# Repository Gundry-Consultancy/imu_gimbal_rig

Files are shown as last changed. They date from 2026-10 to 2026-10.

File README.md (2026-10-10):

# IMU gimbal rig

Pan / tilt / roll rig that carries a whole set of Adafruit IMU, accelerometer
and magnetometer breakouts (3/6/9 DoF) at once, with a cam-driven striker for
tap and double-tap detection testing.

Target sensors: the drivers added in
[adafruit/Adafruit_Wippersnapper_Arduino#839](https://github.com/adafruit/Adafruit_Wippersnapper_Arduino/pull/839)
(ISM330DHCX, ISM330DLC, LIS2MDL, LIS3DH, LIS3MDL, LSM303AGR, LSM303DLH,
LSM6DS3, LSM6DSO32, LSM9DS1). Mostly STEMMA QT breakouts, the odd legacy board,
and one FeatherWing.

## Requirements

- Every sensor is mounted at the same time, on stacked layers of swirly-grid
  plates ([tannewt/swirly-grid](https://github.com/tannewt/swirly-grid)). The
  sides stay open, with a small roof in the middle of the top to whack on. A
  swirly-grid PCB also bolts on through the matching slots.
- Only the centre plate connects to the roll servo and axle. The other plates
  hang off it on central standoffs in line with the roof, not at the edges.
- STEMMA QT sized breakouts, 4 across, plus a Feather-sized place for one
  FeatherWing.
- Hobby servos: MG90S (roll, and an MG90S-size 270° servo for the striker
  cam) and DS3240MG (tilt and pan). Both are measured; see
  `docs/servo-measurements.png`.
- Aim for ±180° on every axis. In practice the servo travel limits it.
- Sensors do not need to sit on the rotation centre. Off-axis
  acceleration is accepted.

## Sensor stack (`make_sensor_stack.py`)

Each deck is a 5 x 4 cell swirly grid (76.2 x 61 mm) with a 3 mm border. The
sides are open.

| Deck | Boards |
|---|---|
| top | 8 portrait QT around a central post with a flared **roof** (24 mm square) for the striker |
| middle | FeatherWing on 10 mm standoffs (clears header pins) + 1 QT, and 4 QT. Its +X / -X end walls (6 mm, with a rib and boss behind the hub) carry the MG90S roll horn and the idler axle. This is the only deck connected to the gimbal. |
| bottom | 8 portrait QT |

That is room for **21 QT boards + 1 FeatherWing**. PR 839 needs 9 breakouts + the wing.

- **Board layout:** boards sit portrait, 4 across, in two rows per deck. Each
  uses the QT connector on its outer edge, so cables leave through the open
  ±Y sides.
- **Fixing:** each board bolts through its top-edge hole pair (every QT board
  has it), with M2.5 screws, 3 mm spacers and nuts.
- **Spines:** a solid strip runs between the two rows on every deck. The upper
  and lower spines (36 x 7 mm standoffs) sit on it, directly under the roof.
- **Clamping:** two M3 bolts at x = ±14 run through the whole stack, with the
  heads on top, just outside the roof, and nuts underneath. The top and bottom
  decks have bosses round the bolt holes (6 mm there instead of 3), so washers
  are optional.
- **Mux:** you'll need a TCA9548A, because of I²C address clashes (several
  LIS3MDL/LSM303/LSM9DS1 parts share addresses). It fits in a spare board spot.

`pack_faces.py` checks the board placements against the slot geometry.

## Tap striker (`make_striker.py`)

**Redesigned 2026-10-10 so the gimbal can tilt all the way over.** The old
hairpin bar hovered just above the roof and limited tilt to ±55°. Now a rigid
hammer arm pivots on top of a tower on the pan yoke. When parked, it swings
up and well clear of the whole tilt sweep.

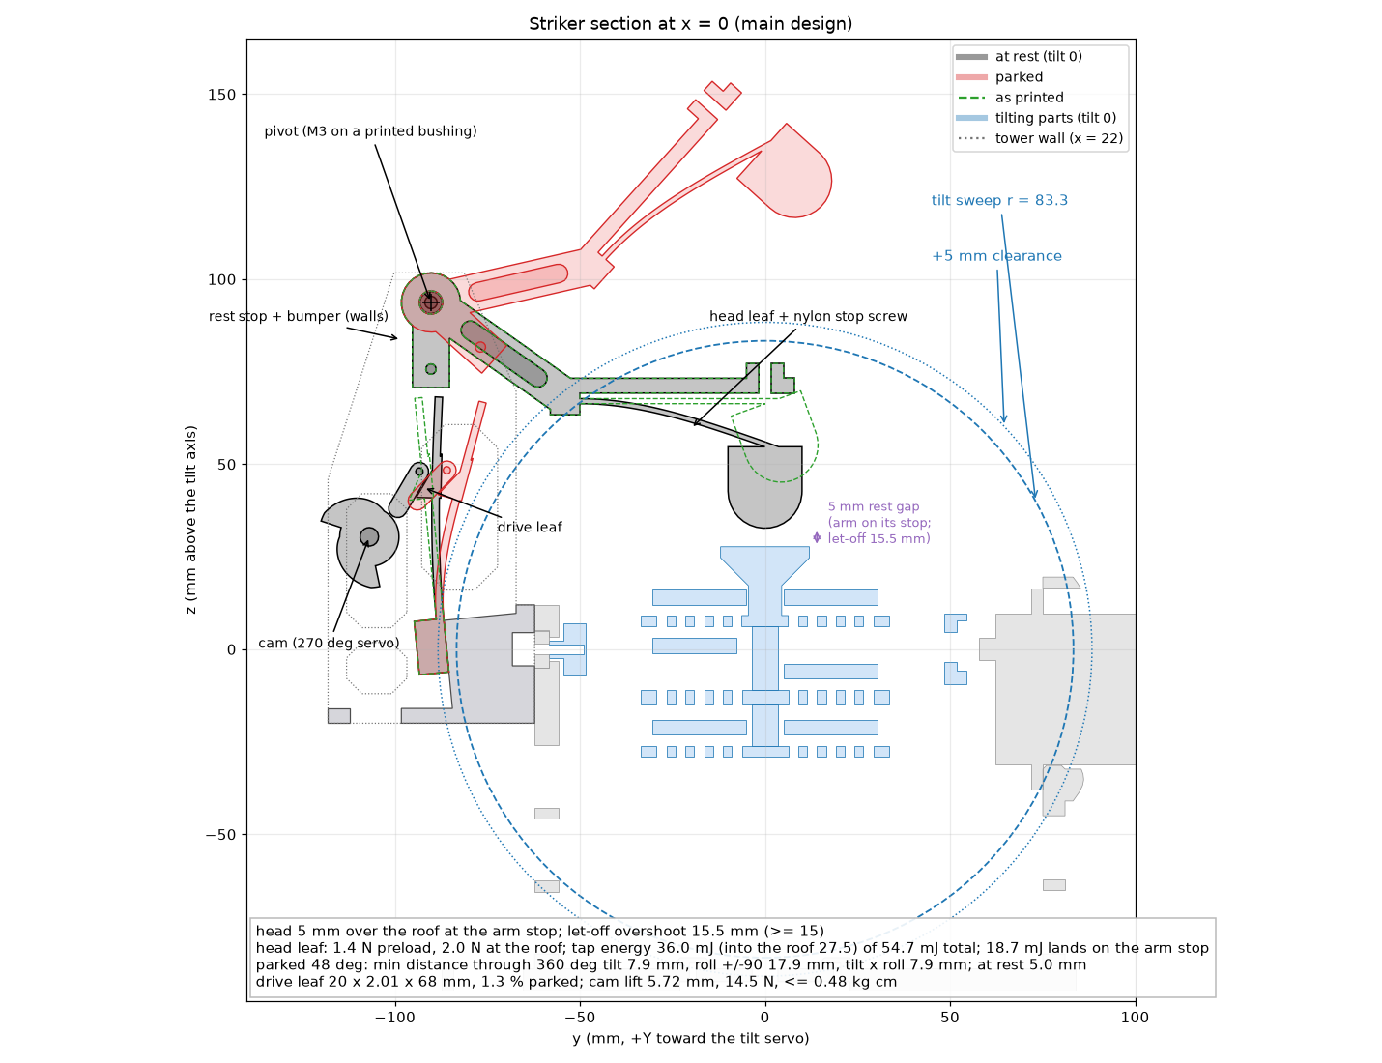
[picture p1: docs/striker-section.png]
striker section


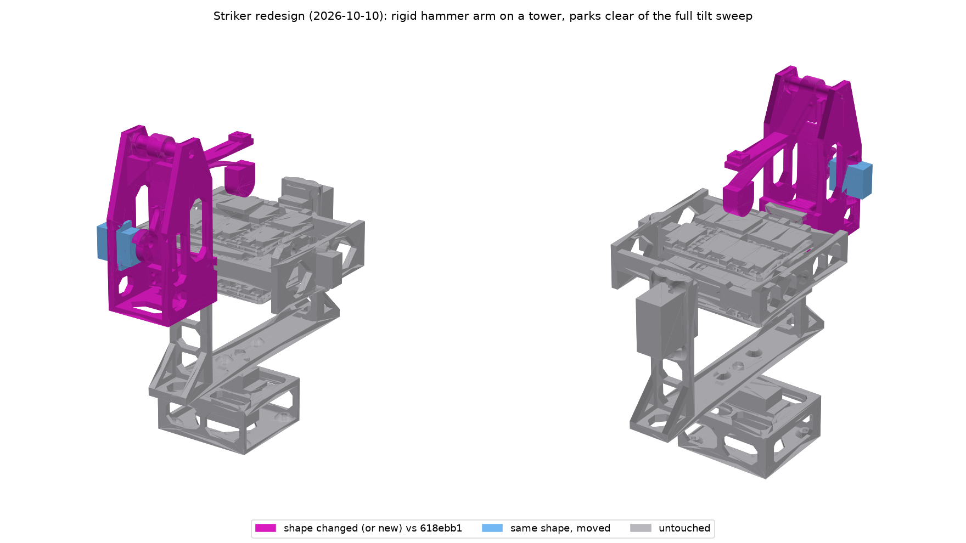
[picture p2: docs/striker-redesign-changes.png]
striker changes


**Parts:**
- **Tower** (`striker_stand`): bolts to the yoke's idler upright with the
  same 4 x M3 as before. Everything on it stays behind the ring band
  (y < −62 mm), so nothing on it can meet the ring when it tilts.
- **Hammer arm** (`striker_arm`): pivots on an M3 x 50 bolt, through a printed
  bushing and two spacers, about 66 mm above the roof.
- **Drive leaf** (`striker_spring`): a PETG strip standing on a seat at the
  bottom of the tower. Its tip fork is pinned (M3) to the arm's tail.
- **Cam:** the 270° servo's two-lobe cam bends the drive leaf through a
  folding pawl.

**How it works:**
- **Rest:** the drive leaf pushes the tail back, and the tail lands on a
  rest stop between the walls (with a 2 mm bumper lip). The hammer head then
  hovers **5 mm above the roof**. The servo carries no load at rest:
  the pawl sits 0.4 mm clear of the cam's base circle.
- **Park:** the cam bends the leaf, which swings the arm **48° up**.
  The parked arm clears everything that moves through the full 360° of tilt.
- **Tap:** at a cliff the pawl drops off the cam. The leaf throws the arm
  down onto its rest stop, and the stop takes the arm's energy.
- **Let-off:** the head sits on its own thin PETG leaf (lost motion). A nylon
  M3 screw in the overarm presses the leaf down, preloading it **1.4 N**
  against the screw. When the arm stops, the head's momentum carries it on
  through the 5 mm gap to the roof (**2.0 N** of leaf force at
  contact). Then it springs back onto the screw. The preload keeps it from
  bouncing back into the roof for a second tap.
- **Energy:** the drop releases **54.7 mJ** in all.
  - **36 mJ** is the head's share. That's what the tap carries
    (**27.5 mJ** is left at the roof after the leaf work).
  - The arm's **18.7 mJ** goes into the tower's rest stop, not the
    sensor stack.
- **Let-off margin:** the head could travel **15.5 mm** past the arm
  stop if the roof weren't there. That's ≥ 3 x the 5 mm gap, so the tap
  always lands.
- **Pawl:** pinned with 1.75 mm filament. It points at the cam centre and
  leans 16° past the cam's force line onto a stop under it. The cam's push,
  its forward drag and gravity all hold it there. On the reverse stroke the
  cliffs fold it up and back, and gravity drops it back.
- **Two lobes in the 270° travel.** Forward is −X rotation (seen from +X,
  the cam turns clockwise). If your servo runs the other way, flip the
  angles in software.

  | Action | Servo |
  |---|---|
  | rest, hammer hovering | 0° |
  | park for a double tap | ~120° |
  | park for a single tap | ~240° |
  | double tap | sweep forward through 125° and 245° (about 0.2 s apart at full MG90S speed) |
  | single tap | from 240°, step past 245° |
  | re-arm | back to 0°, then forward to a park angle |

  **Keep the hammer parked whenever the gimbal moves.**

**Computed for E = 2 GPa** (spring models in `leaf_design()` and
`head_leaf_design()`):

| | |
|---|---|
| drive leaf | 20 x 2.01 x 68 mm. 1.69 N at rest, 5.13 N parked at the pin; 1.3 % peak strain parked. The seat leans back 5.57° so a straight print is preloaded |
| head leaf | 12 x 1.36 x 50 mm, k = 0.12 N/mm, preloaded 11.7 mm by the stop screw; 1.36 % strain at contact |
| arm | 20.2 g; the head is 0.66 of its moment of inertia |
| cam | lift 5.72 mm (r 8 → 13.7). 14.5 N on the pawl when parked (the old bar: 14 N); servo torque ≤ 0.48 kg·cm |

**Clearance** (`striker_limits()` in `make_gimbal.py`: `distToShape`
against everything that moves, 5° steps). Each limit is ≥ 5 mm.

| | tilt 360° (parked) | roll ±90° (parked) | tilt 360° x roll ±45/±90° (parked, 15° steps) | at rest, tilt 0 / roll 0 |
|---|---|---|---|---|
| main | **7.9 mm** (clear through 360°) | 17.9 mm | 7.9 mm | 5.0 mm (the head over the roof) |
| `tall_top` | **7.9 mm** (clear through 360°) | 16.3 mm | 7.9 mm | 5.0 mm (the head over the roof) |

The ring's −Y axle stub is left out of these checks. It only spins inside the yoke's bearing, and its 4.5 mm to the tower's axle-screw pocket is set by the yoke (unchanged).

**At rest, apart from the roof** (main and `tall_top` alike), the nearest
moving part to each striker piece is:
- head: a top-deck QT board, 17.0 mm
- head leaf: 42.0 mm
- arm: 47.6 mm

The rest of the striker is at least 7.9 mm from anything that moves.

**Tuning:**
- The tap energy, contact force, gap and let-off margin are `TAP_ENERGY`,
  `F_CONTACT`, `HOVER` and `OVERSHOOT_MIN` at the top of `make_striker.py`.
  The leaves are re-solved from those values.
- On the bench, the stop-screw nuts trim the head preload. A thin shim on
  the rest-stop lip trims the hover gap.
- **Creep:** PETG relaxes under constant load. The drive leaf only carries
  much load while parked, and the stop screw takes up any creep in the head
  leaf.

**Printing:**
- `striker_arm` and `striker_spring` must be PETG, at 100 % infill.
  - `striker_arm` prints on its side (one 12 mm thick profile).
  - `striker_spring` prints flat, with its lugs and fork up.
- The tower prints upright, floor down. The pivot bosses are downward
  teardrops, and the walls stand vertical.

## Gimbal (`make_gimbal.py`)

Axes: roll = X, tilt = Y, pan = Z, all crossing in the stack. The script
measures the sweep radius of each stage to size the next one out. It then
rotates each stage through 360° against its neighbour, checks the striker
against the roll and tilt ranges, and reports any collision.

| Part | Holds | Servo | Idler |
|---|---|---|---|
| `stack_*` | all the boards | MG90S horn pocket on the middle deck's +X wall | M3 axle boss on the -X wall |
| `tilt_ring_mg90s` | roll servo + 623 bearing | MG90S (measured) | DS3240 horn on the +Y bar, M3 axle on -Y |
| `pan_yoke` | tilt servo + 623 bearing, outer gussets, striker stand pilots | DS3240MG on +Y | pan horn pocket underneath |
| `base` | pan servo | DS3240MG (270° version for ±135°) | open +X end for cables, 4 x M3 bench holes |
| `striker_*` | tower (stand), hammer arm, drive leaf, pawl, cam, pivot bushing + spacers | MG90S-size 270° servo | M3 pivot on a printed bushing |

**Servo mounts:** each mount sets its height from G (tab top to spline top),
taken as you measured it: MG90S 12.0, DS3240 14.0. If a servo sits a little
low, put a washer under its tabs. Every mount has a wire notch at the spline
end, 0.4 mm clearance, lead-in chamfers on both faces and bosses round the
screw pilots; see [Fit fixes](#fit-fixes-after-the-first-test-print).

The overall envelope is about 137 x 226 x 249 mm with the striker at rest
(about 300 mm tall with the hammer parked), and the printed parts weigh
about 376 g solid (305 g with the old striker, 349 g before the fit fixes).

### Fixings

Lengths come from the plate thicknesses in the model. Self-tap means a
machine or self-tapping screw cut straight into the printed pilot hole.

**Near the sensors, use non-magnetic fixings** (nylon, brass, or at least A2
stainless). Steel within a few cm of a magnetometer shows up as hard- and
soft-iron error.

| Where | Fixing | Qty | Notes |
|---|---|---|---|
| **Sensor stack** | M3 x 50 bolt (tall_top: M3 x 55) | 2 | top deck through both spines to the bottom deck at x = ±14; grip 44.3 mm (tall_top 52.2); **brass or nylon preferred** |
| | M3 nut (+ washers, optional) | 2 | nuts under the bottom deck's bosses, heads on the top deck's bosses just outside the roof. With tall_top's M3 x 55, leave the washers out |
| **QT boards** | M2.5 x 10 screw + nut + 3 mm spacer | 2 per board | top-edge hole pair; **nylon**. 9 boards in PR 839 = 18 sets (capacity 21 boards = 42) |
| **FeatherWing** | M2.5 x 10 standoff (F-F) + 2 x M2.5 x 6 screws + nut | 4 | nylon; 10 mm clears male headers |
| **Roll axis** | MG90S horn: supplied centre screw + 2 x M2 x 6 self-tap (arm) | 1 set | middle deck +X wall (4 mm behind the pocket floor) |
| | 623ZZ bearing + M3 x 12 button head + washer | 1 | tilt ring -X end, screw into the middle deck's -X axle boss |
| | MG90S tab screws: supplied, or 2 x M2 x 8–10 self-tap | 2 | tilt ring servo plate (1.7 mm pilots, 10 mm deep in the bosses) |
| **Tilt axis** | DS3240 horn: supplied centre screw + 2 x M2.5 x 8 self-tap (arm) | 1 set | tilt ring +Y bar |
| | 623ZZ bearing + M3 x 12 button head + washer | 1 | yoke -Y upright, screw into the ring's -Y axle boss |
| | DS3240 tab screws: supplied, or 4 x M2.6/M3 x 10–14 self-tap | 4 | yoke +Y plate (2.4 mm pilots, 12 mm deep in the bosses) |
| **Pan axis** | DS3240 horn: supplied centre screw + 2 x M2.5 x 8 self-tap (arm) | 1 set | yoke underside |
| | DS3240 tab screws: supplied, or 4 x M2.6/M3 x 10–12 self-tap | 4 | base plate (10 mm deep in the bosses) |
| | M3 x 16 (or #4 wood) screws, bench | 4 | base foot corners (3.5 mm holes through 6 mm bosses) |
| **Striker** | M3 x 14 (x 16 at most, with a washer) | 4 | tower to the yoke's idler upright (covers the tilt bearing), as before. Plate 10 mm at the bosses + upright 6.4 mm; longer pokes through toward the tilt ring. Reach the heads through the 7 mm holes in the leaf seat |
| | M3 x 50 + M3 nut | 1 | arm pivot: −X wall, `striker_bushing` (the arm and 2 spacers ride on it), +X wall. The nut drops into the hex pocket on the +X wall; tighten until snug, since the bolt clamps the walls onto the bushing, not the arm |
| | M3 x 20 | 1 | drive pin: through the drive leaf's fork slots, self-tapped into the arm's tail (2.8 mm pilot). Leave the head ~0.3 mm off the fork so the pin slides |
| | M3 x 16 | 4 | drive leaf root pad to the seat (self-tap into the 2.8 mm pilots) |
| | **M3 x 30 nylon** + 2 nylon M3 nuts | 1 | head stop screw: down through the overarm, one nut under the boss and one on top. The lower nut sets how far the screw presses the head leaf (11.7 mm preload). **Nylon:** it hangs right over the top deck |
| | MG90S-size 270° servo tab screws: supplied, or 2 x M2 x 8 self-tap | 2 | the tower's −X wall (servo plate) |
| | `striker_cam`: supplied centre screw, horn trimmed to 14 mm and **CA-glued** into the cam | 1 | the cam has no arm pilots |
| | `striker_cam_spline` instead: M2 x 10 centre screw | 1 | counterbored from the cam's front face |
| | 1.75 mm filament, ~12 mm | 1 | pawl pin; melt or flare the ends |
| **Printed horns** (if used) | MG90S: M2 x 8 centre screw; DS3240: M3 x 10 centre screw | per horn | longer than stock, because the printed hub is thicker |

**Bearings:** 2 x 623ZZ (3 x 10 x 4 mm).

**To order:** see [docs/shopping_list.md](docs/shopping_list.md), with quantities rounded to pack sizes.

**Totals for the main design, with 9 QT boards + wing:**
- **M3:**
  - M3 x 50: 3 (2 stack bolts, 1 striker pivot)
  - M3 x 12: 2 (axles)
  - M3 x 14: 4 (striker tower)
  - M3 x 16: 4 (drive leaf pad)
  - M3 x 20: 1 (drive pin)
  - M3 x 30 nylon + 2 nylon nuts: 1 (head stop screw)
  - M3 nuts: 3 (stack bolts, pivot)
  - M3 washers: ~2 (axles; the stack washers are optional)
  - bench screws (M3 x 16): 4
- **M2.5:**
  - M2.5 x 10: 18 (QT boards)
  - M2.5 x 6: 8 (wing)
  - M2.5 x 8 self-tap: 4 (horn arms)
  - M2.5 nuts: 22
  - 3 mm spacers: 18
  - 10 mm F-F standoffs: 4
- **M2:**
  - M2 x 6 self-tap: 2 (MG90S horn arms)
  - M2 x 8 self-tap: 4 (MG90S tabs, if not supplied)
  - M3 x 12 self-tap: 8 (DS3240 tabs, if not supplied)
- **Servo-supplied:** the horn centre screws and tab screws for 2 x MG90S and
  2 x DS3240.
- **Other:** 2 x 623ZZ bearings and a little 1.75 mm filament.

**Horns: two options, one set of parts.** Every horn pocket works either way.

1. **Stock horn.** The pockets are sized for an assumed double-arm horn:
   - MG90S: 36 x 7 mm, 2 mm deep, hub 2.5 mm
   - DS3240: 46 x 8.5 mm, 2.5 mm deep, hub 3.5 mm

   Each pocket has self-tap pilots 3.5 mm in from the arm tips. If your horn's
   holes land elsewhere, drill your own.
2. **Printed horn.** Print `horn_mg90s_printed` (21T) or `horn_ds3240_printed`
   (25T).
   - **Fit:** shaped to fill its pocket exactly, with a moulded spline socket,
     so it fits whatever the stock horns turn out to be.
   - **Screws:** an M2 (MG90S) or M3 (DS3240) screw through the hub into the
     spline, and M2 / M2.5 arm screws into the pocket pilots.
   - **Printing:** print arm-down, socket up, with fine layers (0.1–0.12 mm,
     a 0.25 mm nozzle if you have one).
   - **Fit tuning:** `SPLINE_CLEAR` in `make_gimbal.py` (0.1 mm radial)
     loosens or tightens the spline.

**The striker cam** has both versions too: `striker_cam` takes a stock horn
trimmed to 14 mm, and `striker_cam_spline` has the 21T socket moulded in
(M2 screw from the front, counterbored).

**Fitting a horn, either way:** screw the horn to the part, press it onto the
spline, then drive the centre screw through the part's access hole.

## Fit fixes after the first test print

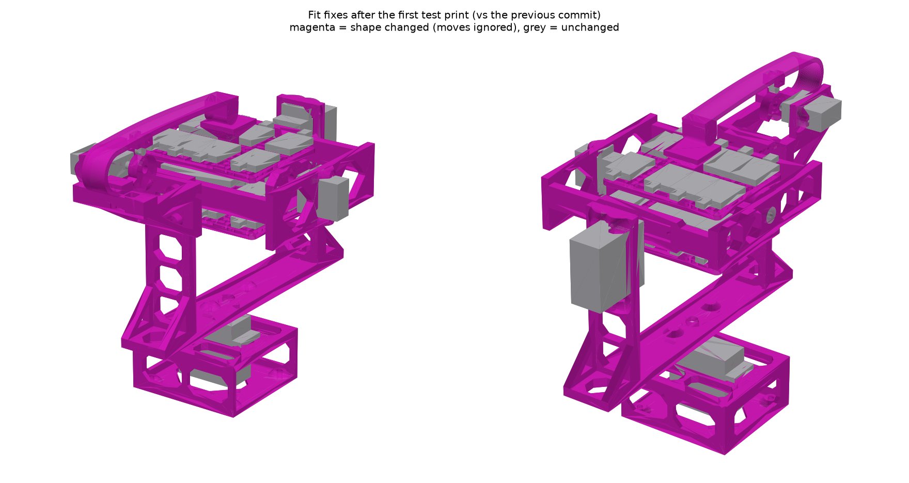
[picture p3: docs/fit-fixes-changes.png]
fit-fix changes


The first print failed in three ways:
- the servos would not go into their plates
- the plates and the tilt ring snapped at the screw pilots when they were
  flexed to get the servos in
- the middle deck's +X (horn) wall snapped along its top edge

Every fix is parametric. The servo-plate values are at the top of
`make_gimbal.py`, and the wall values at the top of `make_sensor_stack.py`.

| Problem | Fix | Parameters |
|---|---|---|
| The cable exit caught on the plate | A wire notch at the spline end of every body cut-out, through the plate and its bosses | `wire_notch` in the `MG90S` / `DS3240` dicts, `MOUSE_EAR_MIN_ARC` |
| The cut-out was too tight | 0.4 mm clearance per side (was 0.25), plus a 1 mm x 45° lead-in chamfer on **both** faces | `SERVO_CUT_CLEAR`, `SERVO_LEADIN` |
| Plates snapped at the pilots | 45° cone bosses on the side away from the tabs double the material round every tab pilot (the seat doesn't move). Bosses were also added at the striker-stand bolts, the stack bolt holes, the bench holes and the yoke's horn-arm pilots | `BOSS_FACTOR`, `BOSS_WALL` |
| The horn wall snapped | The wall is 6 mm thick (4 mm behind the pocket floor, was 2), wider than the horn arm and carried 8 mm above the axis with 45° shoulders. It has a rib and boss behind the hub and a flared root. The pocket has 45° roofs and the access hole is a teardrop, so nothing bridges when it prints walls-up | `WALL_T`, `WALL_ABOVE`, `RIB_*`, `ROOT_FLARE` |
| Thin bearing lips | Both 623 lips are 2.4 mm (were 2.0) | `RING_BRG_PLATE_T`, `YOKE_BRG_T` |
| Heavy parts | Windows in the low-stress webs of the ring, yoke, base and stand, with 45° tops so they print without support | `MAX_BRIDGE` |

**Wire notches and open-sided (mouse-ear) pilots.** A screw pilot sits right
where the cable leaves each servo, so the notch opens one side of that pilot
instead of leaving a paper-thin wall. At least 240° of wall stays round each
opened pilot (measured at mid-wall), and each one sits in a boss twice the
plate thickness.

| Plate | Servo | Notch | Pilots opened into the notch |
|---|---|---|---|
| `tilt_ring_mg90s` (roll) | MG90S | 6.0 mm wide, 1.1 mm past the cut-out (1.5 mm past the body end) | the one spline-end pilot (it's on the centreline) |
| `striker_stand` (cam) | MG90S | same | same |
| `pan_yoke` (tilt) | DS3240 | 8.0 mm wide, out to the tab end (7 mm past the body) | both spline-end pilots, inner side |
| `base` (pan) | DS3240 | same | same |

The MG90S notch is short because the spline-end screw sits on the centreline,
only ~1 mm past the body. If the cable still catches, there are two options:
- put the servo in from the other face (both faces are chamfered)
- lower `MOUSE_EAR_MIN_ARC` and give `wire_notch` a depth in mm. The build
  refuses a notch that opens a pilot past the limit.

**Which face each servo goes in from.** Turn each servo so the spline end (the
cable end) lines up with the notch.

| Servo | Plate | Goes in from | |
|---|---|---|---|
| roll MG90S | tilt ring, +X plate | inside the ring (the tab face), bottom first | the outer face also works (chamfered) |
| tilt DS3240 | yoke, +Y upright | the inner face (toward the ring), bottom first | tab face only |
| pan DS3240 | base, top plate | from above, bottom first | tab face only |
| cam MG90S | striker tower, −X wall | from inside the tower (the tab face), bottom first, before the leaf and cam go in; spline end (cable) up | the other face also works (chamfered) |

**Volume**, for the parts that were lightened or thickened:

| Part | Before (cm³) | After (cm³) | Change |
|---|---|---|---|
| `tilt_ring_mg90s` | 49.2 | 40.7 | −17 % |
| `pan_yoke` | 74.7 | 64.5 | −14 % |
| `base` | 54.9 | 36.0 | −34 % |
| `striker_stand` | 27.2 | 24.2 | −11 % |
| **those four** | **206.0** | **165.4** | **−20 %** |
| `stack_middle_deck` | 21.3 | 27.7 | +30 % (stronger walls) |
| `stack_top_deck` / `stack_bottom_deck` | 16.4 / 11.8 | 16.6 / 12.1 | bolt bosses |

**Envelope:** each middle-deck wall is 2 mm thicker. That makes the ring 4 mm
longer, puts the roll servo 2 mm further out and drops the yoke floor 2 mm.
The rig is now about 137 x 236 x 194 mm (was 132 x 236 x 192). The tilt range
with the striker fitted is unchanged.

**Not changed:**
- The tilt ring still needs supports: it's a closed frame, and its bars float
  above the bed.
- The tilt ring's DS3240 horn-arm pilots keep 3.5 mm behind the pocket floor.
  There's no room to thicken them: the horn is on the outside and the roll
  sweep margin is on the inside.
- The striker-stand pilots in the yoke's idler upright stay at the upright's
  6.4 mm. Only 1.5 mm separates it from the ring, so the stand side got the
  bosses instead.

## Print list

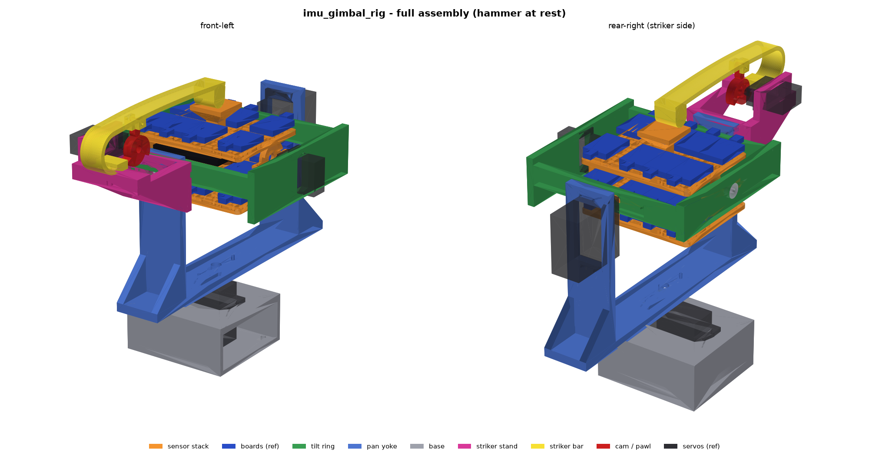
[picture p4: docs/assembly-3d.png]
assembly


All the STLs are in `parts/`. PETG is recommended throughout because it takes
the taps well. **The striker arm and drive leaf must be PETG.**

| STL | Qty | Nozzle | Orientation on the bed | Notes |
|---|---|---|---|---|
| `stack_bottom_deck` | 1 | 0.4 preferred | flat, **bolt bosses up** (upside down) | slots must pass M2.5; on 0.6, regenerate with `SWIRLY_SLOT=2.95` |
| `stack_middle_deck` | 1 | 0.4 preferred | flat, end walls up | carries the roll horn and axle. The horn pocket has 45° roofs and the access hole is a teardrop, so no supports; slot note as above |
| `stack_top_deck` | 1 | 0.4 preferred | flat, roof up | the roof flare is 45°, so no supports; slot note as above |
| `stack_spine_lower` | 1 | 0.6 | on its 36 x 7 face | **11.1 mm** tall (bottom ↔ middle deck) |
| `stack_spine_upper` | 1 | 0.6 | on its 36 x 7 face | **17.1 mm** tall (middle ↔ top deck); 25 mm in `variants/tall_top` |
| `tilt_ring_mg90s` | 1 | 0.6 | flat | **still needs supports** under the side bars and bearing plate (they sit ~10–15 mm up; it's a closed frame). Windows, bosses and pocket roofs are all 45°. Drill the 1.7 mm servo pilots |
| `pan_yoke` | 1 | 0.6 | on its side (32 mm face down) | the U profile lies flat, so no supports; windows have 45° tops (either side down); ream the 623 pocket if tight |
| `base` | 1 | 0.6 | on its closed end wall | open box, no supports; windows have 45° tops |
| `striker_stand` | 1 | 0.6 | **upright, floor down** (as it sits on the yoke) | the tower: walls stand vertical, the pivot bosses are downward teardrops and the rest stops have 45° undersides, so no supports. Windows have 45° tops. Drill the small pilots |
| `striker_arm` | 1 | 0.4 preferred | **on its side** (the 12 mm thick profile flat) | **PETG**, 100 % infill. The head leaf is 1.36 mm thick (its stiffness goes as thickness cubed; the stop screw trims the preload) |
| `striker_spring` | 1 | 0.4 preferred | **flat on its plain (+Y) face**, lugs and fork up | **PETG**, 100 % infill. The drive leaf: its 2.01 mm thickness sets the drive force (thickness cubed) |
| `striker_bushing` | 1 | 0.4 | standing on end | 6 mm tube for the M3 pivot bolt |
| `striker_spacer` | 2 | 0.4 | standing on end | either side of the arm's hub |
| `striker_pawl` | 1 | **0.4 needed** | flat on a 4.4 mm face | 1.9 mm pin hole must swing freely; pin is 1.75 mm filament. **Reprint it:** it is 14 mm long now (was 9) |
| `striker_cam` | 1 | 0.4 preferred | flat, **horn pocket up** | takes a stock horn trimmed to 14 mm; a crisp cliff edge gives a clean drop |
| `striker_cam_spline` | (alt.) | **0.4 needed** | counterbored face down, hub up | 21T socket moulded in; use instead of `striker_cam` |
| `horn_mg90s_printed` | 0–1 | **0.4 needed** (0.25 better) | arm down, socket up | 0.3 mm deep spline teeth; only if the stock roll horn doesn't fit |
| `horn_ds3240_printed` | 0–2 | **0.4 needed** | arm down, socket up | only if the stock tilt/pan horns don't fit |

**Nozzle key:**
- **0.6:** resolution doesn't matter. Thicker lines make these stronger and
  faster; drill or ream the small holes.
- **0.4 preferred:** fits or force depend on accuracy. A 0.6 works with the
  adjustment noted.
- **0.4 needed:** fine features (splines, the pawl pin) that a 0.6 smears.

The core set is 15 parts (16 prints with the second spacer), plus the optional printed horns. Print the horns
with fine layers (0.1–0.12 mm). Print one horn first and test it on a servo
before printing the others (`SPLINE_CLEAR`).

**Spine names were swapped before 2026-10-10.** Older exports of
`stack_spine_lower` were really the 17.1 mm upper spine, and vice versa.
Check the height before using an older print.

## Assembly order

Centre every servo (power it at mid travel) before you fit its horn. Each
horn goes on the same way: screw the horn to the part, press it onto the
spline, then drive the centre screw through the part's access hole.

1. **Test-fit each servo in its plate** before anything else. Put it in
   bottom first, from the face in the table above, with the cable end at the
   notch. Drill the pilots if they're tight.
2. **Base:** drop the pan DS3240 into the base from above. The cable leaves
   through the open +X end. Fit the 4 tab screws, then screw the base to the
   bench.
3. **Yoke:**
   - Put the tilt DS3240 into the +Y upright from the inside (bottom first,
     outward). Fit its 4 tab screws.
   - Press a 623 into the -Y upright from the outside.
   - Screw the pan horn into the underside pocket and press it onto the pan
     spline. Drive its centre screw down through the floor's access hole now,
     while nothing is above it.
4. **Tilt ring:**
   - Put the roll MG90S into the +X plate from inside the ring. Fit its 2 tab
     screws.
   - Press a 623 into the -X bearing plate from the outside.
   - Screw the tilt horn into the +Y bar's pocket.
5. **Sensor stack:**
   - Fit the boards to the decks.
   - Stack the decks: bottom deck (bosses down), lower spine, middle deck,
     upper spine, top deck (bosses up). Clamp them with the two M3 bolts.
   - Screw the roll horn to the middle deck's +X wall.
6. **Stack into the ring:**
   - Press the roll horn onto the MG90S spline and fit its centre screw
     through the wall's access hole.
   - At the -X end, fit an M3 x 12 + washer through the ring's 623 into the
     middle deck's axle boss.
7. **Ring into the yoke:**
   - Press the tilt horn onto the tilt spline and fit its centre screw through
     the bar's access hole.
   - At -Y, fit an M3 x 12 + washer through the yoke's 623 into the ring's
     axle boss.
8. **Striker** (everything goes into the tower before it goes onto the yoke):
   - Put the cam MG90S into the tower's −X wall from inside, bottom first,
     spline end (cable) up. Fit its 2 tab screws.
   - Pin the pawl to the drive leaf's lugs with filament. It should swing
     freely and fall back onto its stop.
   - Screw the drive leaf's root pad to the seat (4 x M3 x 16), lugs and
     pawl toward the servo.
   - Put the bushing through the arm's hub, with a spacer either side. Hold
     the arm between the walls and push the M3 x 50 through the −X wall,
     the bushing and the +X wall, into the nut in its pocket. Tighten until
     snug. The arm should swing freely.
   - Bend the leaf's fork onto the tail (the leaf leans back about 5.5° when
     free). Drive the M3 x 20 pin through one fork slot, self-tap it through
     the tail and out through the other slot. Leave the head ~0.3 mm clear,
     so the pin can slide.
   - Fit the nylon stop screw down through the overarm with a nut under the
     boss. Turn it until the head leaf is pressed down 11.7 mm (the head's
     face is level), then lock it with the top nut.
   - Fit the cam with the servo at 0°: the pawl tip just clears the base
     circle, 45° up from the cam's +Y side.
   - Bolt the tower to the yoke's -Y upright (4 x M3 x 14, reached through
     the holes in the leaf seat). This covers the tilt axle screw, so fit the
     tower last.
   - Check the hover gap: the head's face should sit 5 mm above the roof. To
     trim it, shim the rest-stop lip, where the tail lands.

## Variants

| Folder | What's different |
|---|---|
| [`variants/tall_top`](variants/tall_top/README.md) | Upper spine 25 mm. The top deck, roof and striker sit 7.9 mm higher. Only `stack_spine_upper` and `striker_stand` are new prints. |

## Files

| File | What |
| --- | --- |
| `swirly_grid.py` | Pure-Python swirly-grid geometry + hole-pattern fit checker (`python swirly_grid.py 2 4`) |
| `pack_faces.py` | Portrait QT board placement options on a swirly grid |
| `make_sensor_stack.py` | Sensor stack decks, spines, roof, board layout, reference board envelopes |
| `make_striker.py` | Striker: drive-leaf and head-leaf spring models, hammer arm (rest / parked / as printed), pawl, cam, tower |
| `make_gimbal.py` | Full gimbal + striker, per-part STEP/STL in `parts/`, clearance checks, `imu-gimbal-assembly.FCStd` |
| `make_swirly_plate.py` | Flat printable swirly plate (env `SWIRLY_ROWS`, `SWIRLY_COLS`, `SWIRLY_SLOT`) |
| `make_carrier.py` | Older standalone flat plate with Feather bosses (not used by the gimbal) |
| `preview_swirly.py` | Matplotlib 2D preview |
| `docs/mechanical_data.md` | Board hole/IC positions for the PR 839 sensors, Feather spec, servo dimensions |

Generate with FreeCAD 1.1 (`C:\dev\software\FreeCAD\bin\freecadcmd.exe`):

```
freecadcmd -c "exec(open('make_gimbal.py').read(), {'__file__': 'make_gimbal.py', '__name__': '__main__'})"
```

## Notes

- A 1.0" x 0.7" STEMMA QT board (holes 0.8" x 0.5" apart) cannot land all four
  screws in the swirly grid at once. Three holes fit in 32 placements on a
  3x3 grid, and two holes fit in hundreds. Plan on 2–3 screws per board.
- Slots print at 2.75 mm (nominal 2.54 mm) so M2.5 screws pass on FDM.

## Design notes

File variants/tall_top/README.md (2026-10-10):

# Variant: tall_top

This is the main design with more room between the middle and top decks. The
upper spine goes from 17.1 mm to **25 mm**. The bottom deck and lower spine
are unchanged, since the bottom deck isn't attached to the gimbal.

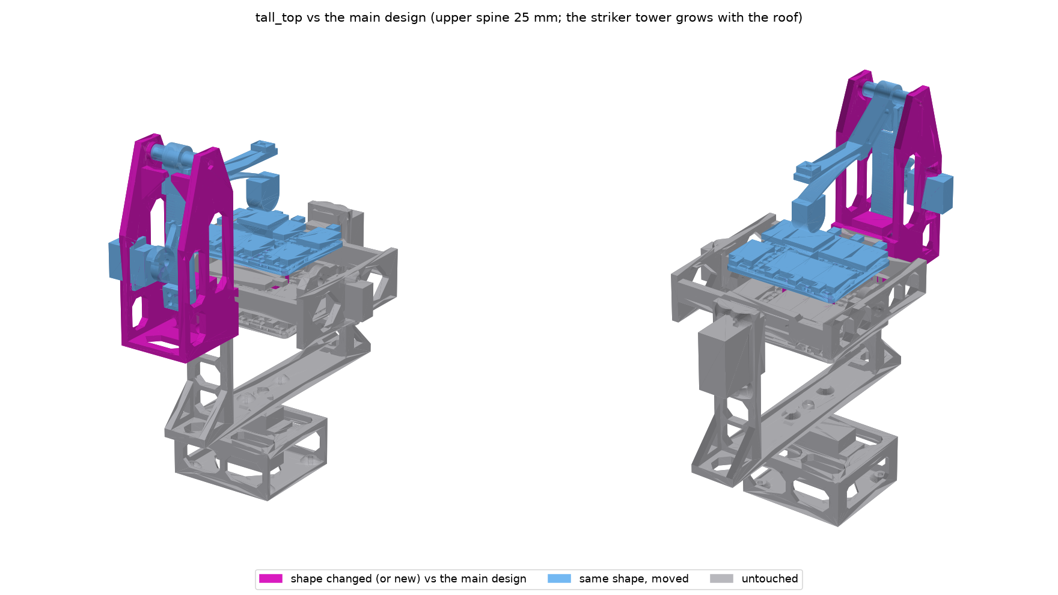
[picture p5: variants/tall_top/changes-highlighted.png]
changes


## What changed

**Modified parts (print these):**

| Part | Change |
|---|---|
| `stack_spine_upper` | 17.1 → **25.0 mm** tall |
| `striker_stand` | the striker tower is 7.9 mm taller (overall 121.7 → 129.6 mm). Its walls, leaf seat and servo plate all move up with the roof |

**Same parts, sitting 7.9 mm higher:** `stack_top_deck` (and its roof), and
the whole striker mechanism: `striker_arm`, `striker_spring`,
`striker_pawl`, `striker_cam` / `striker_cam_spline`, `striker_bushing`,
`striker_spacer` and the cam servo. The STLs are the same as the main
design's.

**Unchanged:**
- The middle deck and its roll walls, the roll axis, tilt ring, pan yoke, base,
  bottom deck, lower spine and horns (all as in the main design, including the
  2026-10-10 fit fixes).
- The ring and yoke sizes are pinned to the main build (`../../build_info.json`).

**Striker numbers are the same as the main design** (2026-10-10 redesign;
see the main README):
- The head hovers 5 mm above the roof at rest.
- The arm parks 48° up.
- Tap energy is 36 mJ of 54.7 mJ total; the arm's 18.7 mJ lands on the
  tower's rest stop.
- Let-off overshoot is 15.5 mm.

**Clearance checks:**
- All checks pass.
- **Roll through 360°:** the higher top deck's connectors clear the unchanged
  tilt ring by 2.4 mm. The main design allows 4 mm, so allow less cable slack
  on the top deck if you roll it all the way round. Within the MG90S's ±90°
  there's more room.
- **Striker (parked):**
  - **tilt clear through 360°**, min distance 7.9 mm
  - roll ±90°: 16.3 mm
  - tilt x roll ±45/±90°: 7.9 mm
- **Striker at rest:** 5.0 mm (the head over the roof). Apart from the roof: head 17.0 mm to the nearest QT board, head leaf 42.0 mm, arm 47.6 mm.

**Hardware differences from the main fixings list:**
- **Stack bolts:** M3 x 55 instead of x 50. The grip is 52.2 mm with the deck
  bolt bosses, so leave the washers out (the bosses replace them).
- **Striker:** the same fixings as the main design. The old `tall_top` M3 x 22
  pad screws are no longer used.

## If you've already printed the main design

Print only `stack_spine_upper` and `striker_stand` from `parts/` here.
Everything else carries over.

## Regenerate

From the repo root, after a main build (which writes `build_info.json`):

```
GIMBAL_OUT=variants/tall_top GIMBAL_PIN=build_info.json STACK_UPPER_GAP=25 freecadcmd -c "exec(open('make_gimbal.py').read(), {'__file__': 'make_gimbal.py', '__name__': '__main__'})"
```

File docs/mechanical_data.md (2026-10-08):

# Mechanical reference data

Coordinates are mm from the board's lower-left corner, in the orientation the
Eagle `.brd` draws it. Hole and IC positions were parsed from the Adafruit PCB
repos. All boards are 1.6 mm FR4 with R2.54 corners and 2.5 mm plated M2.5
holes unless a row says otherwise.

## STEMMA QT 1.0" x 0.7" (25.4 x 17.78) family

- **4-hole pattern:** (2.54, 2.54), (22.86, 2.54), (2.54, 15.24), (22.86, 15.24). The holes are 20.32 x 12.70 apart.
- **2-hole pattern:** only (2.54, 15.24) and (22.86, 15.24), along the top edge, because a header row runs along the bottom.
- **QT connectors:** centred on the left and right short edges.

| Chip (driver) | Board / PID | Holes | IC centre |
|---|---|---|---|
| ISM330DHCX | #4502 | 2 (top) * | (12.70, 8.89) * |
| LIS2MDL | #4488 | 4 (bottom pair are 2.54 non-plated) | (12.70, 8.89) |
| LIS3DH | #2809 QT, **portrait 17.78 x 25.4**, QT on top/bottom edges | 4, same pattern turned 90° | (8.89, 12.70) |
| LIS3MDL | #4479 | 4 | (12.70, 8.89) |
| LSM6DSOX+LIS3MDL | #4517 | 4 | 6DOX (12.446, 7.112), 3MDL (12.255, 10.922) |
| LSM6DS3TR-C+LIS3MDL | #5543 | 4 | 6DS3 (12.446, 7.112), 3MDL (12.255, 10.922) |
| LSM6DS33+LIS3MDL | #4485 | 4 | 6DS33 (12.70, 9.398), 3MDL (12.70, 6.160) |
| LSM303AGR | #4413 | 4 | (12.70, 8.89) |
| LSM6DS3TR-C | #4503 | 2 (top) | (12.70, 8.89) |
| LSM6DS33 | #4480 | 4 | (12.70, 8.89) |
| LSM6DSO32 | #4692 | 2 (top) * | (12.70, 8.89) * |
| LSM9DS1 | #4634 Rev C | 2 (top) | **(11.176, 8.128)** off-centre |

\* Taken from the LSM6DSOX #4438 board, which Adafruit says has an identical layout.

**Chips with no Adafruit board:** the ISM330DLC (the driver uses Adafruit_LSM6DSL) and the plain LSM6DS3 (use the TR-C).

## Legacy / non-QT

| Chip | Board / PID | Outline | Holes | IC centre |
|---|---|---|---|---|
| LIS3DH | #2809 original | 20.32 x 20.32 | (2.54, 17.78), (17.78, 17.78) | (10.16, 10.16) |
| LSM303DLHC | #1120 (no QT version exists) | 22.86 x 20.32 | (2.54, 17.78), (20.32, 17.78) | (11.684, 10.16) |
| LSM303DLHC + L3GD20H | 9-DoF #1714 / 10-DoF #1604 | 38.1 x 22.86 | 4 at 33.02 x 17.78 | LSM303 (28.461, 10.873) |
| LSM303DLHC | Flora #1247 | Ø ~16.5 round | none (sewable pads) | (8.255, 8.255) |
| LSM9DS1 | #3387 Rev A | 33.02 x 20.32 | 4 at 27.94 x 15.24 | (16.51, 10.16) |

## FeatherWing / Feather

- **Board:** probably the ISM330DHCX + LIS3MDL FeatherWing **#4569**. The #4565 LSM6DSOX version shares its layout.
- **Outline:** 50.80 x 22.86.
- **Holes:** (2.54, 2.54), (2.54, 20.32), (48.26, 2.54), (48.26, 20.32), giving 45.72 x 17.78 spacing. The USB-end pair is plated 2.5 mm and the other pair is non-plated 2.54 mm.
- **IC centres on #4569:** ISM330DHCX (27.94, 11.43) and LIS3MDL (22.86, 11.43).
- **Header rows:** y = 1.27 (x 6.35–44.45) and y = 21.59 (x 16.51–44.45).

## Swirly grid fit (2 x 4 plate, `swirly_grid.find_fits`)

| Pattern | Placements |
|---|---|
| QT 4-hole 20.32 x 12.70 | **0**. 3 of the 4 holes fit, so use 2–3 screws. |
| QT 2-hole 20.32 | 268 |
| Feather 45.72 x 17.78 (all 4) | 88 |
| LSM9DS1 legacy 27.94 x 15.24 | 176 |
| 9/10-DoF 33.02 x 17.78 | 0 |
| LIS3DH / LSM303DLHC legacy 2-hole | 3300 / 880 |

## Servos

| Servo | Body L x W x H | Tab length | Hole c-c | Tab underside from body bottom | Spline | Travel | Torque |
|---|---|---|---|---|---|---|---|
| MG90S (**measured**) | 22.7 x 12.3 x 32.0 (to spline top) | 32.2 | 27.5 (single row) | ~16.8; tab top to spline top 11.7–12 | 21T | 180° | 2.2 kg·cm @ 6 V |
| DS3240MG (**measured**) | 40.5 x 20.5 x 46.2 (to spline top) | 54.5 | 48.5–48.6 x 9.5–10 | 28.2; tab 3.08; tab top to spline top 14 | 25T | 180° **or** 270° (same body) | 36–45 kg·cm |
| MG995 | 40.7 x 19.7 x 42.9 | 54 | 48–49.5 x 9.5–10 | 28 | 25T | ~180° | 10 kg·cm @ 6 V |
| DSC55MG (9imod?) | 39.9 x 20.1 x 46.0 | ~54? | unpublished: **measure** | ? | 25T | 270° (180° variant exists) | 43–58 kg·cm, 6–8.4 V HV |

DS3240 STEP model: https://cdn.shopify.com/s/files/1/0673/6848/5000/files/DS3240.stp

**About the measured values:**
- **Source:** hand-measured on 2026-10-08. The readings run 0.1–0.2 mm
  generous, deliberately, for fit.
- **Tab top to spline top:** the CAD uses this as measured directly (MG90S 12.0,
  DS3240 14.0), not base-to-spline minus base-to-tab minus tab (12.7 / 14.8),
  because the generous readings add up.
- **Still to measure:** horn sizes (P–S on `servo-measurements.png`) and the
  DS3240 tab hole diameter.

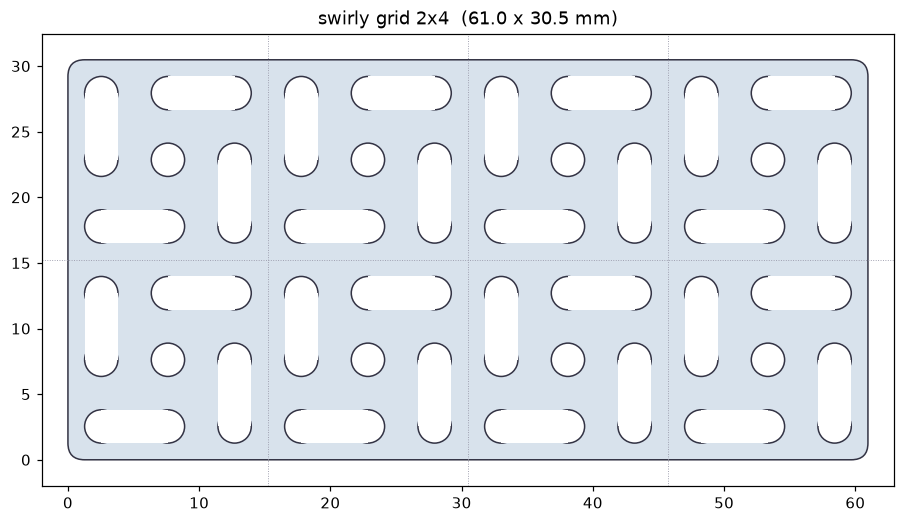
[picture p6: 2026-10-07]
swirly-plate-2x4-preview.png

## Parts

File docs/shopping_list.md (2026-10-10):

# Shopping list

This list is for the main design with 9 QT boards and the FeatherWing, plus
the `tall_top` lengths where they differ. The "Order" column rounds up to
common pack sizes and adds spares.

**Material:** fixings marked *non-magnetic* sit near the sensors. Buy nylon or
brass for those. A2 stainless will do at a pinch, but plain or zinc steel
will not.

## Already have (2026-10-10)

- M2 self-tapping, 6 mm and 8 mm: for the MG90S horn arms and the MG90S /
  cam-servo tabs
- M2.5 x 8 self-tapping: for the DS3240 horn arms
- 623ZZ bearings (on order)
- 1.75 mm filament, for the pawl pin

## Amazon UK basket for next-day delivery (checked 2026-10-10, Bristol BS16)

The board fixings are left out: steel screws for now, then nylon or brass
on slower shipping (see below). These items were showing "fastest delivery
Tomorrow, 11 Oct". Next-day delivery may need Prime or a delivery fee, and
there is a same-day order cutoff.

| Qty | Item | Price | Covers |
|---|---|---|---|
| 1 | [640 pcs M3 socket cap kit, 304 stainless, 6–30 mm + nuts + washers (B0FHJMDC2D)](https://www.amazon.co.uk/dp/B0FHJMDC2D) | £6.29 | M3 x 10 (DS3240 tabs, printed-horn centres), x 12 (axles, or longer DS3240 tab screws), x 14 or x 16 (striker tower: x 16 at most, with a washer), x 16 (drive-leaf pad, bench), x 20 (striker drive pin), nuts (incl. the pivot nut), washers |
| 1 | [M3 x 50 socket cap, 304 stainless, 20-pack (B0FLYHPK3J)](https://www.amazon.co.uk/dp/B0FLYHPK3J) | £5.99 | the two stack bolts (44.3 mm grip) and the striker's arm pivot. `tall_top` now needs M3 x 55 for the stack: its grip is 52.2 mm with the deck bosses, used without washers |
| (opt.) | [M2 x 10 pan head, 304 stainless, 100-pack (B0FJFY1CGX)](https://www.amazon.co.uk/dp/B0FJFY1CGX) | £5.29 | centre screws for a printed MG90S horn / `striker_cam_spline` only. Stock horns use the servo's own screw |

That's about **£12** (or about £18 with the M2 screws).

**What's not truly non-magnetic:** the stack bolts and axle screws above are
304 stainless, which is only weakly magnetic. Swap them for brass later if
the magnetometers show it.

## Sensor-board fixings: slow shipping (nylon or brass)

You're using steel screws for now. Expect the magnetometers to read a
hard-iron offset until these are swapped, and redo the mag calibration after
the swap.

| Need | Item | Notes |
|---|---|---|
| 36 | M2.5 x 12 pan head screw, nylon or brass | 2 per QT board, for 9 boards; more if you fill extra spots |
| 36 | M2.5 nut, nylon or brass | under each deck |
| 36 | M2.5 x 3 mm spacer (or 3 x 1 mm washers each) | under each board |
| 4 | M2.5 x 10 F-F standoff, nylon or brass | FeatherWing (clears the header pins) |
| 8 | M2.5 x 6–8 screw, nylon or brass | FeatherWing standoffs, top and bottom |
| 1 (+ spares) | **M3 x 30 pan head screw, nylon** | striker head stop screw (it hangs over the top deck, so nylon). New with the 2026-10-10 striker |
| 2 (+ spares) | **M3 nut, nylon** | lock the stop screw either side of the overarm boss |

**Tidier alternative:** M2.5 **3 + 6 mm brass male-female standoffs** (36),
plus M2.5 x 6 screws and nuts. The male end goes through the deck slot with a
nut underneath, and the board screws into the top. That replaces the spacers
and the long screws. A ~300-piece M2.5 nylon standoff kit plus a bag of
M2.5 x 12 nylon screws also covers the whole table.

**If using M2.5 x 12:** under the middle deck, snip the screw tips flush with
the nut. Uncut, they reach to within ~0.5 mm of the bottom deck's board
screws.

## Full itemised list

| Order | Item | Material | Need | Used for |
|---|---|---|---|---|
| 4 | **M3 x 50** bolt | brass or nylon *(non-magnetic)* | 2 | stack bolts, main design |
| 4 | **M3 x 55** bolt | brass or nylon *(non-magnetic)* | 2 | stack bolts, `tall_top` (skip if not building it) |
| 10 | M3 nut | brass or nylon *(non-magnetic)* | 2 | stack bolts |
| 20 | M3 washer | nylon *(non-magnetic)* | 2–6 | axles; stack-bolt washers are optional now (deck bosses) |
| 10 | **M3 x 12** button head | A2 stainless | 2 | roll and tilt axles through the 623s |
| 20 | **M3 x 10** socket or button head | A2 / any | 10 | DS3240 tab screws (8, cut into the 2.4 mm pilots; x 12 bites deeper into the new bosses), printed DS3240 horn centres (2) |
| 10 | **M3 x 14** socket or button head | A2 / any | 4 | striker tower to yoke through the 10 mm stand bosses (x 16 at most, with a washer) |
| 10 | **M3 x 16** socket head | any | 8 | striker drive-leaf pad (4), base to bench (4) |
| 5 | **M3 x 20** socket head | A2 / any | 1 | striker drive pin, self-tapped into the arm's tail |
| (from the M3 x 50 pack) | **M3 x 50** socket head | A2 | 1 | striker arm pivot (through the tower walls and the printed bushing) |
| 10 | M3 nut | steel / A2 | 5 | base to bench (4), striker pivot (1, in the +X wall's hex pocket) |
| 5 | **M3 x 30 pan head, nylon** + 2 nylon M3 nuts | nylon *(non-magnetic)* | 1 | striker head stop screw |
| 25 | M2.5 x 10 pan head | nylon *(non-magnetic)* | 18 | QT boards (2 each) |
| 10 | M2.5 x 6 pan head | nylon *(non-magnetic)* | 8 | FeatherWing standoffs (both ends) |
| 30 | M2.5 nut | nylon *(non-magnetic)* | 18 | QT boards |
| 25 | M2.5 x 3 mm spacer | nylon *(non-magnetic)* | 18 | under each QT board |
| 8 | M2.5 x 10 F-F standoff | nylon *(non-magnetic)* | 4 | FeatherWing (clears the header pins) |
| 5 | M2 x 8 machine screw | any | 1 | printed MG90S horn centre (into the servo's threaded spline) |
| 5 | M2 x 10 machine screw | any | 1 | `striker_cam_spline` centre |
| 1 | CA glue (superglue) | - | - | the trimmed horn into `striker_cam` |

**One kit instead:** the six nylon M2.5 lines are all covered by one
**M2.5 nylon standoff / screw / nut kit** (the ~300-piece hex kits with
6–20 mm standoffs).

**The horn centre screws are machine screws.** They go into the servo
spline's tapped hole, so self-tapping screws won't do there. Use the ones
supplied with the servos for stock horns.

**No springs or rubber bands to buy:** both striker springs (the drive leaf and the head leaf) are printed PETG.

**Not fixings, but needed to run it:**
- a TCA9548A I2C mux
- STEMMA QT cables (one per board, 100–200 mm)
- the servos: 2 x MG90S (one 270°), 2 x DS3240MG

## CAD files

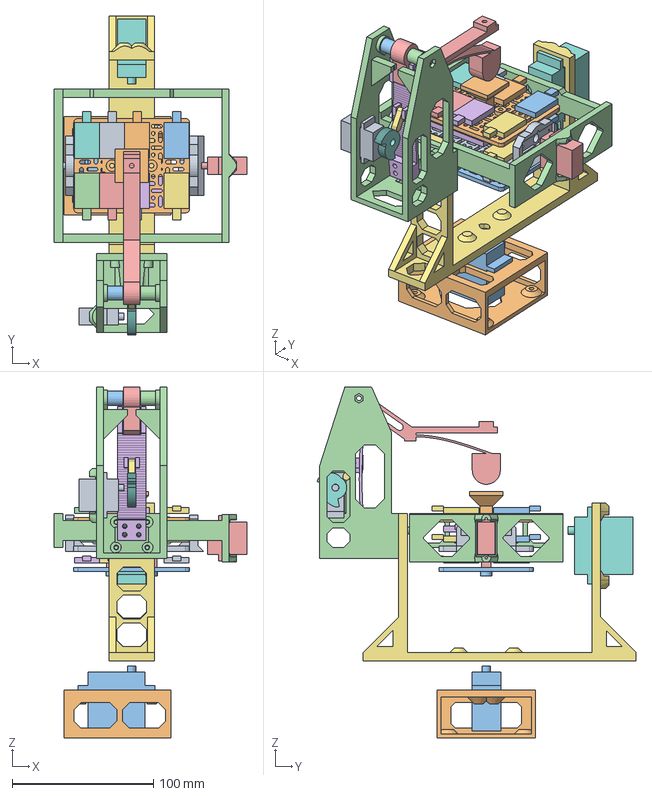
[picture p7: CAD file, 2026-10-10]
imu-gimbal-assembly.FCStd
136.6 x 226.0 x 248.7 mm
Middle deck + roll walls (wing + 5 QT)
Top deck (8 QT) + roof
Bottom deck (8 QT)
Upper spine
Lower spine
REF bottom_QT_low1
REF bottom_QT_low2
REF bottom_QT_low3
REF bottom_QT_low4
REF bottom_QT_high1
REF bottom_QT_high2
REF bottom_QT_high3
REF bottom_QT_high4
REF middle_FeatherWing
REF middle_QT_low1
REF middle_QT_high1
REF middle_QT_high2
REF middle_QT_high3
REF middle_QT_high4
REF top_QT_low1
REF top_QT_low2
REF top_QT_low3
REF top_QT_low4
REF top_QT_high1
REF top_QT_high2
REF top_QT_high3
REF top_QT_high4
Tilt ring (MG90S tab 16.8 mm)
REF MG90S roll servo (tab 16.8 mm)
REF 623ZZ roll idler
Pan yoke
REF standard servo, tilt (MG995 / DS3240)
REF 623ZZ tilt idler
Base
REF standard servo, pan (DS3240 270)
Striker stand (tower)
Striker hammer arm (at rest, head 5 mm over the roof)
Striker drive leaf (at rest)
Striker pawl
Striker cam
REF MG90S-size 270 deg servo (cam)
Striker bushing
Striker spacer
Striker spacer001

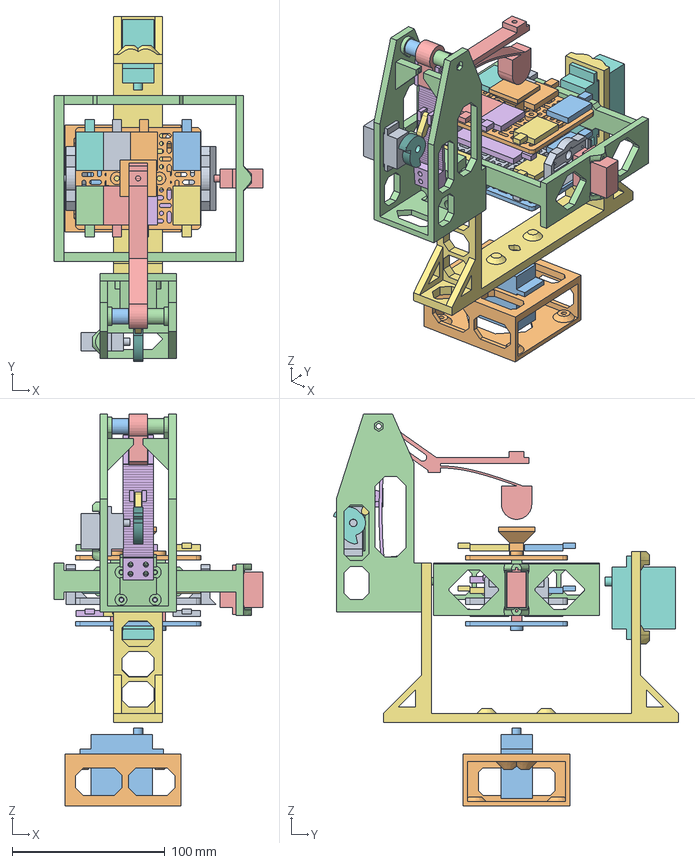
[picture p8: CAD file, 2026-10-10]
variants/tall_top/imu-gimbal-assembly.FCStd
136.6 x 226.0 x 256.6 mm
Middle deck + roll walls (wing + 5 QT)
Top deck (8 QT) + roof
Bottom deck (8 QT)
Upper spine
Lower spine
REF bottom_QT_low1
REF bottom_QT_low2
REF bottom_QT_low3
REF bottom_QT_low4
REF bottom_QT_high1
REF bottom_QT_high2
REF bottom_QT_high3
REF bottom_QT_high4
REF middle_FeatherWing
REF middle_QT_low1
REF middle_QT_high1
REF middle_QT_high2
REF middle_QT_high3
REF middle_QT_high4
REF top_QT_low1
REF top_QT_low2
REF top_QT_low3
REF top_QT_low4
REF top_QT_high1
REF top_QT_high2
REF top_QT_high3
REF top_QT_high4
Tilt ring (MG90S tab 16.8 mm)
REF MG90S roll servo (tab 16.8 mm)
REF 623ZZ roll idler
Pan yoke
REF standard servo, tilt (MG995 / DS3240)
REF 623ZZ tilt idler
Base
REF standard servo, pan (DS3240 270)
Striker stand (tower)
Striker hammer arm (at rest, head 5 mm over the roof)
Striker drive leaf (at rest)
Striker pawl
Striker cam
REF MG90S-size 270 deg servo (cam)
Striker bushing
Striker spacer
Striker spacer001

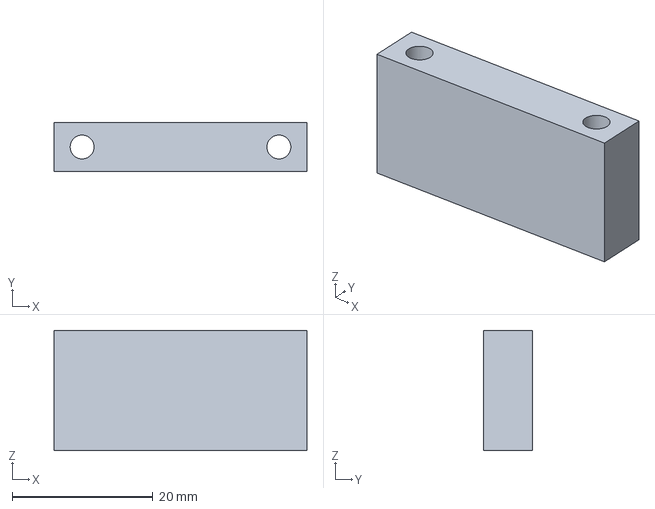
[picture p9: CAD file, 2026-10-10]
parts/stack_spine_upper.step
36.0 x 7.00 x 17.1 mm

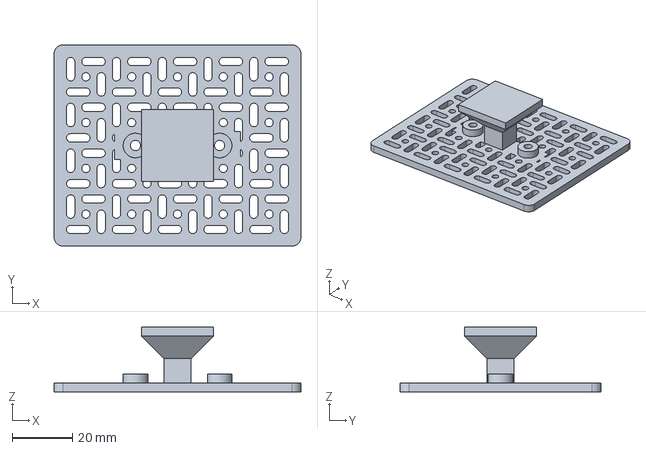
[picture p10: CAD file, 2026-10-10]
variants/tall_top/parts/stack_top_deck.step
82.2 x 67.0 x 21.6 mm

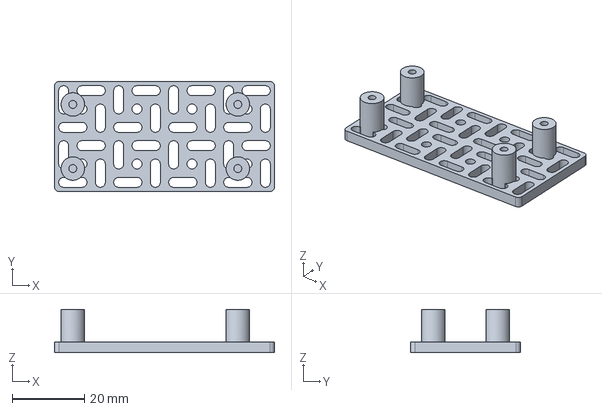
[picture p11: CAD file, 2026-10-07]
carrier-swirly-2x4-feather.step
61.0 x 30.5 x 12.0 mm

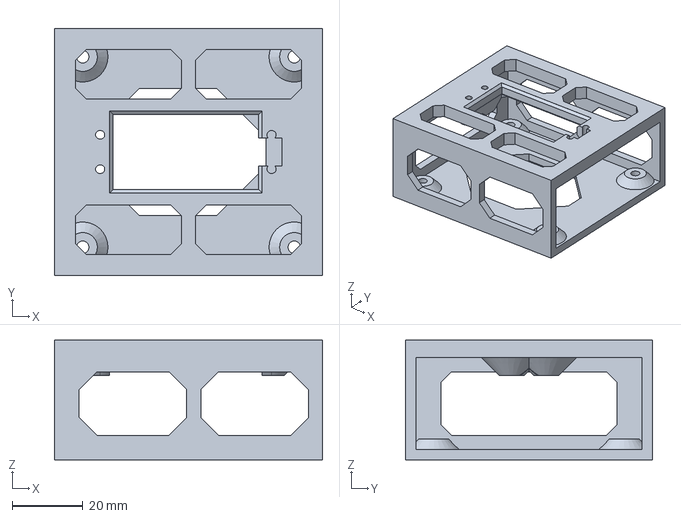
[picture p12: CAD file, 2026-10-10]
variants/tall_top/parts/base.step
76.0 x 70.0 x 34.0 mm

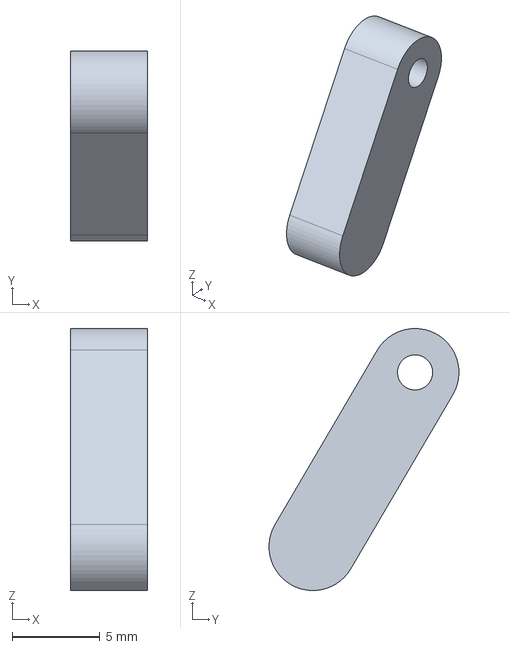
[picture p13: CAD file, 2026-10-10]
parts/striker_pawl.step
4.40 x 10.8 x 14.9 mm

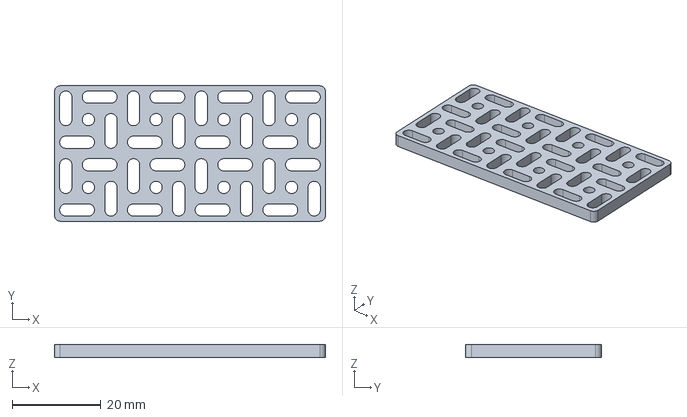
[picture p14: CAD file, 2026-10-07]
swirly-plate-2x4.step
61.0 x 30.5 x 3.00 mm

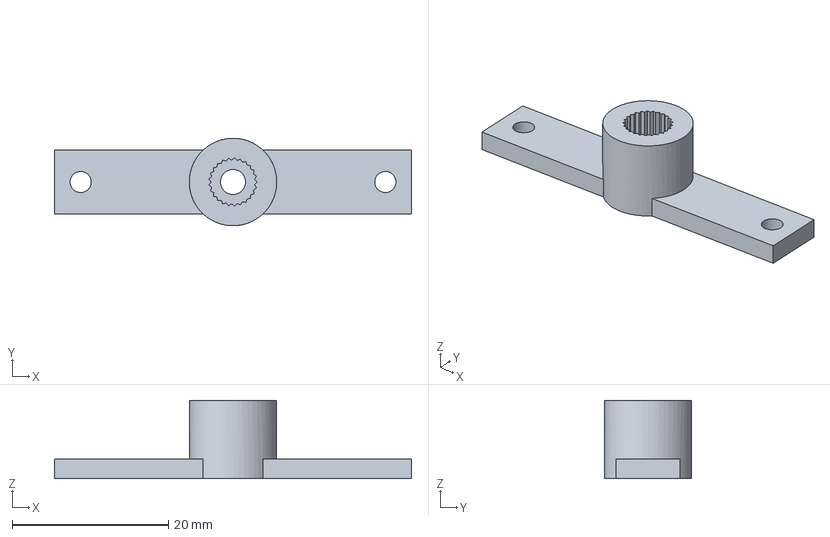
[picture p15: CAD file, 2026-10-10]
variants/tall_top/parts/horn_ds3240_printed.step
45.7 x 11.2 x 10.0 mm

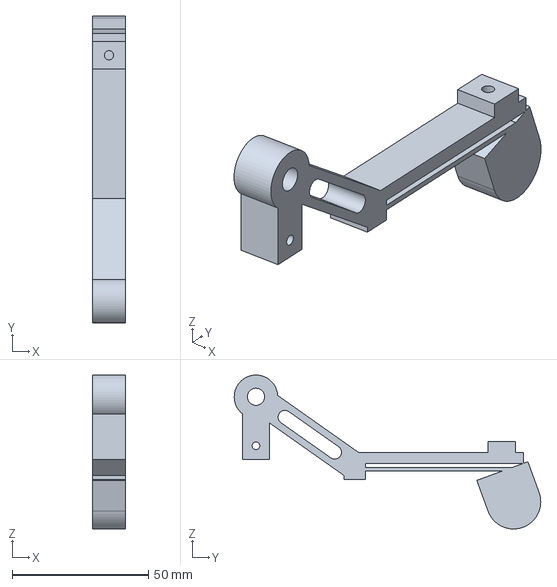
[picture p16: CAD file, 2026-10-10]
parts/striker_arm.step
12.0 x 112.6 x 56.6 mm

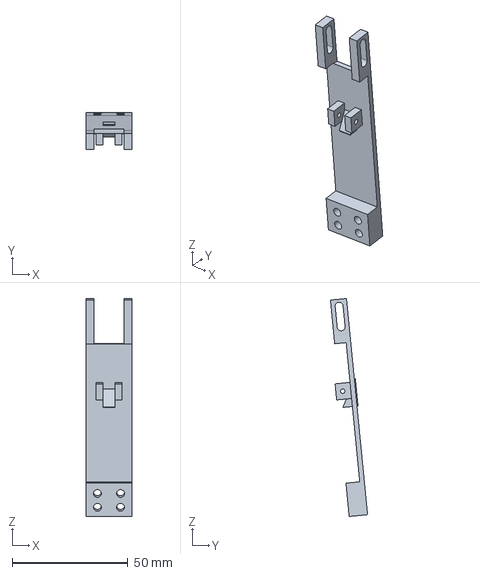
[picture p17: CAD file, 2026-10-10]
variants/tall_top/parts/striker_spring.step
20.0 x 16.1 x 94.3 mm

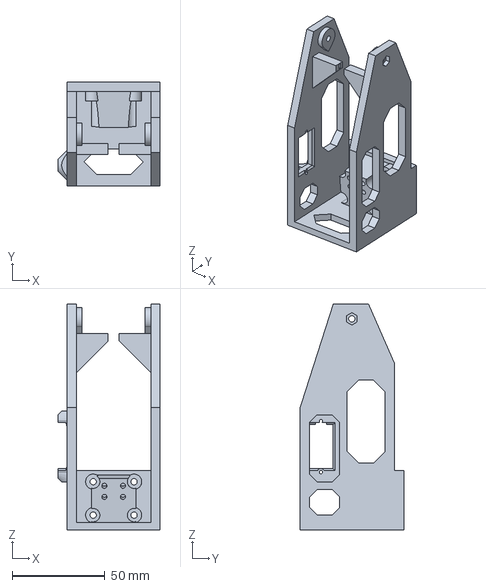
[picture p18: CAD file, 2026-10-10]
parts/striker_stand.step
55.0 x 55.8 x 121.7 mm

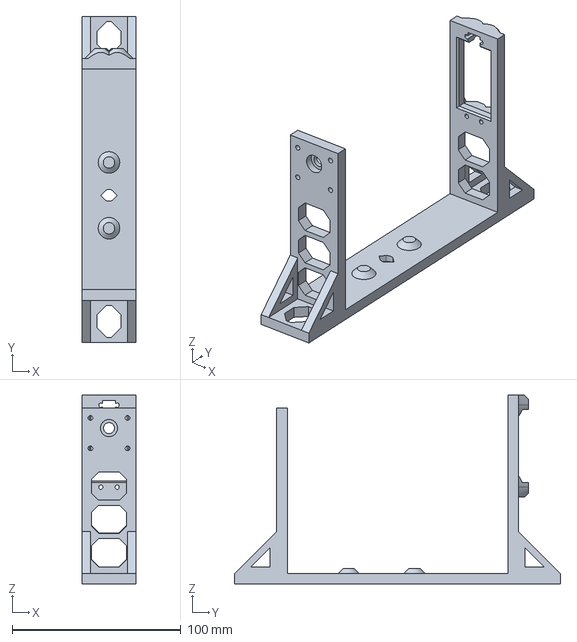
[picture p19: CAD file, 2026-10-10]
variants/tall_top/parts/pan_yoke.step
32.0 x 193.3 x 111.8 mm

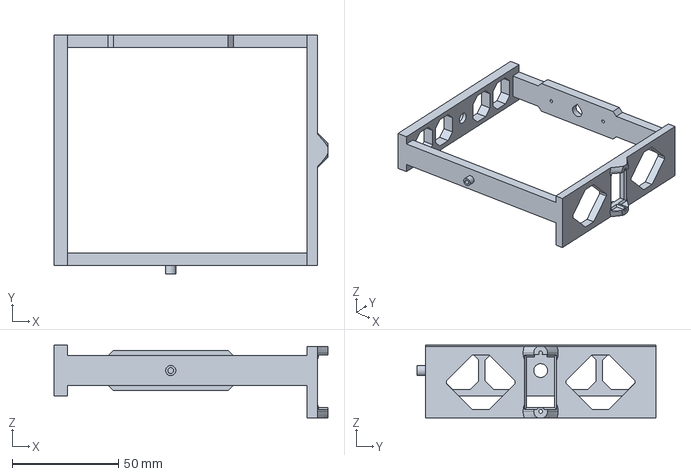
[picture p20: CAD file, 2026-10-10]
parts/tilt_ring_mg90s.step
129.1 x 112.6 x 34.3 mm

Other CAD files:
parts/stack_top_deck.step
variants/tall_top/parts/striker_cam.step
parts/striker_spacer.step
variants/tall_top/parts/striker_pawl.step
carrier-swirly-2x4-feather.FCStd
carrier-swirly-2x4-feather.stl
parts/base.step
parts/base.stl
parts/horn_ds3240_printed.step
parts/horn_mg90s_printed.step
parts/pan_yoke.step
parts/pan_yoke.stl
parts/stack_bottom_deck.step
parts/stack_bottom_deck.stl
parts/stack_middle_deck.step
parts/stack_middle_deck.stl
parts/stack_spine_lower.step
parts/stack_spine_upper.stl
parts/stack_top_deck.stl
parts/striker_arm.stl
parts/striker_bushing.step
parts/striker_cam.step
parts/striker_cam.stl
parts/striker_cam_spline.step
parts/striker_cam_spline.stl
parts/striker_pawl.stl
parts/striker_spring.step
parts/striker_spring.stl
parts/striker_stand.stl
parts/tilt_ring_mg90s.stl
parts/tilt_ring_mg90s_tab16.step
swirly-plate-2x4.FCStd
swirly-plate-2x4.stl
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

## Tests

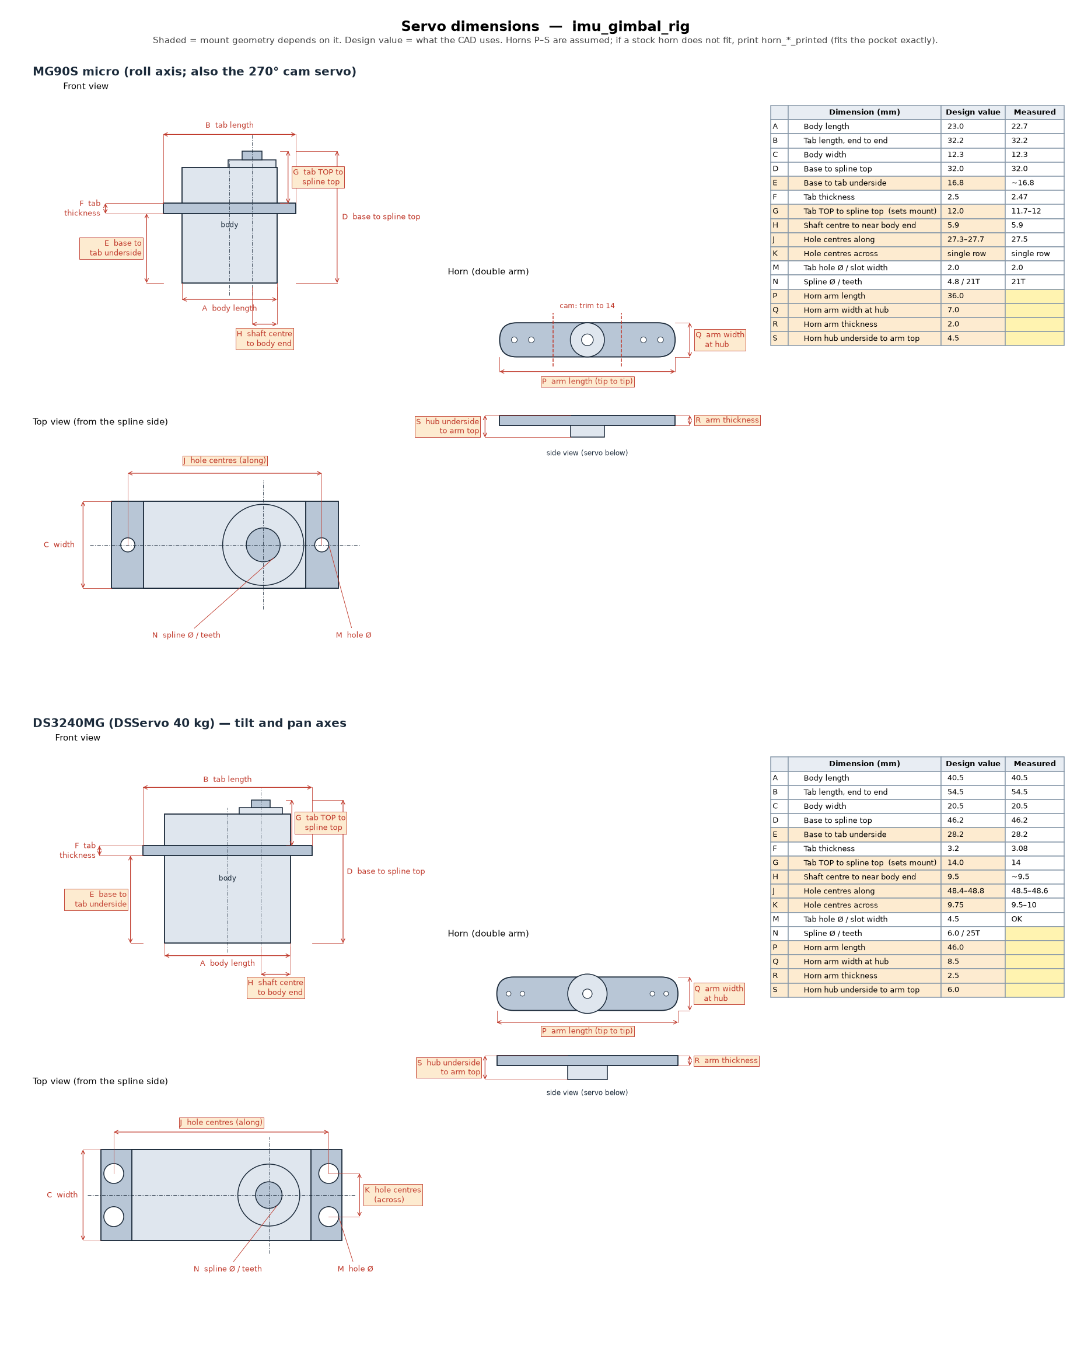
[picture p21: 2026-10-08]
docs/servo-measurements.png

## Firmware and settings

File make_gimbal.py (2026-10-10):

"""Pan / tilt / roll gimbal around the sensor stack. Run with freecadcmd.

    freecadcmd -c "exec(open('make_gimbal.py').read(), {'__file__': 'make_gimbal.py', '__name__': '__main__'})"

Global frame: origin is the axis intersection (middle of the sensor stack), +X is the roll axis,
+Y is the tilt axis, +Z is the pan axis (up).

Parts (exported to parts/):
  stack_middle_deck, stack_top_deck, stack_bottom_deck, stack_spine_upper, stack_spine_lower
                                the sensor stack (see make_sensor_stack.py); only the middle deck's
                                end walls carry the MG90S horn (+X) and the 623 idler axle (-X)
  striker_arm, striker_spring, striker_pawl, striker_cam, striker_stand, striker_bushing, striker_spacer
                                cam-driven tap striker on a tower on the yoke (see make_striker.py)
  tilt_ring_mg90s                holds the roll MG90S and the -X 623 bearing;
                                standard-servo horn on +Y bar, idler axle on -Y
  pan_yoke                      holds the standard tilt servo (+Y) and the -Y 623 bearing;
                                pan horn on the underside
  base                          holds the standard pan servo

The servo, bearing and board solids are reference envelopes for clearance
checks. They are not printed.
"""

import json
import math
import os
import sys

import FreeCAD as App
import Part
import Mesh

HERE = os.path.dirname(os.path.abspath(__file__))
sys.path.insert(0, HERE)
import make_sensor_stack as ss  # noqa: E402

V = App.Vector
# GIMBAL_OUT: output folder for a design variant (default: this folder). GIMBAL_PIN: a
# build_info.json from the base build; its ring / yoke sizes are reused so a variant
# leaves the gimbal untouched (the clearance checks still run against it).
OUT_DIR = os.environ.get("GIMBAL_OUT", HERE)
PARTS_DIR = os.path.join(OUT_DIR, "parts")
PIN = os.environ.get("GIMBAL_PIN")
PIN_MIN_CLEAR = 1.5         # a pinned variant may eat into the sweep margins, but not below this

# --- servos ---------------------------------------------------------------
# Measured by hand 2026-10-08 (see docs/servo-measurements.png). Letters match the drawing.
# Readings run 0.1-0.2 mm generous (fit allowance), so they are used as-is.
# spline_above_tab (G) sets the mount position: the directly measured G is used
# (D - E - F reads ~0.8 mm more because the generous readings compound).
# offset: shaft centre from body centre along the long axis = A/2 - H.
MG90S_TAB = 16.8                                   # E, base to tab underside
MG90S_G = 12.0                                     # G, tab top to spline top (11.7-12 measured)
MG90S = dict(L=23.0,                               # A 22.7 measured, allow 23
             W=12.3, H=32.0, case_top=4.0,         # C, D
             tab_len=32.2, tab_t=2.5,              # B, F
             holes=(27.3, 27.7), hole_across=0.0,  # J 27.5 (+/-0.2 slot), single row
             pilot=1.7, offset=22.7 / 2 - 5.9,     # M 2.0 (M2 self-tap pilot), H 5.9
             spline_r=2.4,                         # N 21T, ~4.8
             spline=dict(n=21, d=4.8, tooth=0.3, engage=3.5, screw=2.2, head=4.2),   # M2 centre screw
             pilot_wall=1.0,                       # min wall kept round a closed tab pilot
             wire_notch=dict(width=6.0, depth=None),   # see MOUSE_EAR_MIN_ARC below
             # P-S assumed (stock horn) -- or print horn_mg90s_printed, which fits this pocket exactly
             horn=dict(len=36.0, width=7.0, depth=2.0, hub=2.5, centre=6.0, pilot=1.6, arm_screw=2.2))
DS3240 = dict(L=40.5, W=20.5, H=46.2, case_top=4.5,   # A, C, D
              tab_len=54.5, tab_t=3.2,                # B, F (3.08 measured)
              holes=(48.4, 48.8), hole_across=9.75,   # J 48.5-48.6, K 9.5-10
              pilot=2.4, offset=40.5 / 2 - 9.5,       # H ~9.5
              spline_r=3.0,
              spline=dict(n=25, d=6.0, tooth=0.3, engage=4.0, screw=3.2, head=6.0),   # M3 centre screw
              spline_above_tab=14.0,                  # G measured (D - E - F reads 14.8)
              pilot_wall=1.2,
              wire_notch=dict(width=8.0, depth="tab"),
              # P-S assumed (stock horn) -- or print horn_ds3240_printed, which fits this pocket exactly
              horn=dict(len=46.0, width=8.5, depth=2.5, hub=3.5, centre=7.0, pilot=2.0, arm_screw=2.7))
STANDARD = DS3240      # tilt and pan servos (an MG995 would need its own measurements)

# --- servo plate fit tuning (after the first test print, 2026-10-10) --------
# The servos would not go in: the cable exit at the spline end hit the plate, the cut-out
# was tight, and the plates snapped at the screw pilots when flexed.
#
# Wire notch: an extension of the body cut-out at the spline (+x) end, through the whole
# plate and its bosses, centred on the servo's long axis. Per servo, in the dicts above:
#   wire_notch=dict(width=..., depth=...)   depth in mm beyond the cut-out, "tab" (to the
#   tab end) or None (as deep as MOUSE_EAR_MIN_ARC allows for a pilot on the centreline).
# Where the notch reaches a screw pilot it opens the pilot's side ("mouse ear") instead of
# leaving a paper-thin wall; at least MOUSE_EAR_MIN_ARC degrees of wall stay round it, and
# the boss below keeps it strong. Defaults:
#   DS3240  8.0 wide to the tab end. It runs between the two pilots (9.75 apart) and opens
#           each one's inner side by ~118 deg at mid-wall (~86 deg at the hole). (7 mm would leave a 0.2 mm wall; a closed
#           1.2 mm wall would cap the notch at 4.95 mm wide.)
#   MG90S   6.0 wide; its spline-end pilot sits on the centreline only ~1 mm past the
#           body, so the notch stops where the pilot keeps 240 deg of wall (~1.1 mm deep,
#           reaching ~1.5 mm past the body end). The MG90S can also go in from the other face.
SERVO_CUT_CLEAR = 0.4       # body cut-out clearance per side (was 0.25)
SERVO_LEADIN = 1.0          # 45 deg lead-in chamfer on the body cut-out, on both faces
MOUSE_EAR_MIN_ARC = 240.0   # deg of wall a wire notch must leave round a pilot it opens,
MOUSE_EAR_AT = 0.5          #   measured this far out from the pilot (mid-wall)
BOSS_WALL = 2.4             # pilot boss wall (6 perimeters at 0.4)
BOSS_FACTOR = 2.0           # local thickness at a tab pilot = BOSS_FACTOR x plate thickness
MAX_BRIDGE = 8.0            # longest flat ceiling allowed in a lightening window


def mg90s(tab_height):
    s = dict(MG90S)
    s["spline_above_tab"] = MG90S_G
    s["tab_height"] = tab_height
    return s


# --- bearing 623ZZ (3 x 10 x 4) -------------------------------------------
BRG_OD, BRG_W = 10.0, 4.0
BRG_POCKET = 10.15
LIP_HOLE = 6.5
AXLE_BOSS_D = 4.8   # touches inner race only
M3_PILOT = 2.8

# --- layout ------------------------------------------------------------------
BODY_HALF_X = ss.body_half_x()             # outer face of each cradle end wall
SWEEP_MARGIN = 4.0                          # beyond the measured sweep radius (cable slop)
RING_BAR_T = 6.0
RING_BAR_HALF_Z = 7.0
RING_BRG_PLATE_T = 6.4   # 4 mm bearing pocket + 2.4 mm lip (6 perimeters; was 2)
RING_GAP = 1.5
RING_HORN_BOSS = 9.5     # the +Y bar grows to +/- this round the tilt horn (teardrop roofs fit)

YOKE_PLATE_T = 6.0       # tilt servo plate
YOKE_BRG_T = 6.4         # idler upright: 4 mm bearing pocket + 2.4 mm lip
YOKE_HALF_X = 16.0
YOKE_GAP = 1.5
YOKE_FLOOR_T = 6.0

SERVO_PLATE_T = 5.0
STAND_BOLTS = ((-11.0, 6.0), (11.0, 6.0), (-11.0, -12.0), (11.0, -12.0))   # striker stand on the idler upright (x, z)


# --- helpers ---------------------------------------------------------------
def box(x0, x1, y0, y1, z0, z1):
    return Part.makeBox(x1 - x0, y1 - y0, z1 - z0, V(x0, y0, z0))


def cyl(r, p0, p1):
    d = p1 - p0
    return Part.makeCylinder(r, d.Length, p0, d)


def placed(shape, origin, xdir, zdir):
    """Map a local shape (x = servo long axis / horn arm, z = shaft direction) into the world."""
    xdir, zdir = V(xdir).normalize(), V(zdir).normalize()
    ydir = zdir.cross(xdir)
    m = App.Matrix(xdir.x, ydir.x, zdir.x, origin.x,
                   xdir.y, ydir.y, zdir.y, origin.y,
                   xdir.z, ydir.z, zdir.z, origin.z,
                   0, 0, 0, 1)
    s = shape.copy()
    s.transformShape(m)
    return s


def servo_envelope(s):
    """Local frame: spline top at origin, shaft along +z, long axis along x (body centre at -offset)."""
    cx = -s["offset"]
    body = box(cx - s["L"] / 2, cx + s["L"] / 2, -s["W"] / 2, s["W"] / 2, -s["H"], -s["case_top"])
    tz1 = -s["spline_above_tab"]
    tabs = box(cx - s["tab_len"] / 2, cx + s["tab_len"] / 2, -s["W"] / 2, s["W"] / 2, tz1 - s["tab_t"], tz1)
    spline = Part.makeCylinder(s["spline_r"], s["case_top"], V(0, 0, -s["case_top"]))
    return body.fuse([tabs, spline]).removeSplitter()


def prism(pts2d, origin, u, v, n, n0, n1):
    """Polygon in the (u, v) plane at origin, extruded along n from n0 to n1 (world vectors)."""
    u, v, n = V(u), V(v), V(n)
    pts = [origin + u * a + v * b + n * n0 for a, b in pts2d]
    return Part.Face(Part.makePolygon(pts + [pts[0]])).extrude(n * (n1 - n0))


def window_pts(u0, u1, v0, v1):
    """Lightening window outline in (u, v), v = print-up. 45 deg corners top and bottom keep
    any flat ceiling under MAX_BRIDGE, so it prints without support either way up."""
    w, h = u1 - u0, v1 - v0
    c = min(h / 2, max(1.0, (w - MAX_BRIDGE) / 2))
    pts = [(u0 + c, v0), (u1 - c, v0), (u1, v0 + c), (u1, v1 - c), (u1 - c, v1), (u0 + c, v1), (u0, v1 - c), (u0, v0 + c)]
    return [p for i, p in enumerate(pts) if (abs(p[0] - pts[i - 1][0]) + abs(p[1] - pts[i - 1][1])) > 1e-6]


def row_windows(a, b, n, web=3.0):
    """Split [a, b] into n window spans separated by webs."""
    w = (b - a - (n - 1) * web) / n
    return [(a + i * (w + web), a + i * (w + web) + w) for i in range(n)]


def servo_pilots(s):
    """Tab screw pilots in servo-local coords: (x_near_body, x_far, y, r)."""
    cx = -s["offset"]
    h0, h1 = s["holes"]
    ys = [0.0] if s["hole_across"] == 0 else [-s["hole_across"] / 2, s["hole_across"] / 2]
    return [(cx + side * h0 / 2, cx + side * h1 / 2, y, s["pilot"] / 2) for side in (-1, 1) for y in ys]


def wire_notch(s):
    """(x0, x1, half_width) of the wire notch in servo-local coords, or None. Checks the mouse-ear rule."""
    n = s.get("wire_notch")
    if not n:
        return None
    cx = -s["offset"]
    x0 = cx + s["L"] / 2 + SERVO_CUT_CLEAR
    hw = n["width"] / 2
    half_open = math.radians((360.0 - MOUSE_EAR_MIN_ARC) / 2)
    x_tab = cx + s["tab_len"] / 2
    x1 = x_tab if n["depth"] in (None, "tab") else x0 + n["depth"]
    for xa, xb, y, r in servo_pilots(s):
        if xa < x0:
            continue                                   # far-end pilot
        rr = r + MOUSE_EAR_AT
        if abs(y) < hw:                                # pilot centre inside the notch band
            stop = xa - rr * math.cos(half_open)
            if n["depth"] is None:
                x1 = min(x1, stop)
            elif x1 > stop + 1e-6:
                raise ValueError(f"wire notch opens a centreline pilot past {MOUSE_EAR_MIN_ARC} deg")
        elif abs(y) - hw < rr and x1 > xa - rr:        # notch runs past, opening the pilot's side
            opened = 2 * math.degrees(math.acos((abs(y) - hw) / rr))
            if opened > 360.0 - MOUSE_EAR_MIN_ARC:
                raise ValueError(f"wire notch opens a pilot by {opened:.0f} deg")
    return (x0, x1, hw) if x1 > x0 + 0.2 else None


def _rect_wire(x0, x1, y0, y1, z):
    return Part.makePolygon([V(x0, y0, z), V(x1, y0, z), V(x1, y1, z), V(x0, y1, z), V(x0, y0, z)])


def servo_plate(s, x_ext, y_ext, thickness=SERVO_PLATE_T):
    """Mount plate in servo-local frame, tabs resting on its +z face.

    Returns (plate, cutters, bosses). The bosses double the thickness round every tab pilot on
    the -z side (away from the tabs); they are 45 deg cones so they print in any orientation.
    Fuse them after any bounding-box based layout, then apply the cutters (body cut-out with
    lead-in chamfers on both faces, wire notch, pilots)."""
    z1 = -s["spline_above_tab"] - s["tab_t"]
    z0 = z1 - thickness
    hb = (BOSS_FACTOR - 1) * thickness
    zb = z0 - hb
    plate = box(x_ext[0], x_ext[1], y_ext[0], y_ext[1], z0, z1)
    cx, c, ch = -s["offset"], SERVO_CUT_CLEAR, SERVO_LEADIN
    bx0, bx1, by0, by1 = cx - s["L"] / 2 - c, cx + s["L"] / 2 + c, -s["W"] / 2 - c, s["W"] / 2 + c
    pilots = servo_pilots(s)
    cut = [box(bx0, bx1, by0, by1, zb - 1, z1 + 1)]
    # lead-in chamfers on both faces, kept pilot_wall clear of every pilot
    lead = [Part.makeLoft([_rect_wire(bx0, bx1, by0, by1, z1 - ch), _rect_wire(bx0 - ch, bx1 + ch, by0 - ch, by1 + ch, z1)], True),
            box(bx0 - ch, bx1 + ch, by0 - ch, by1 + ch, z1 - 0.01, z1 + 1),
            Part.makeLoft([_rect_wire(bx0, bx1, by0, by1, z0 + ch), _rect_wire(bx0 - ch, bx1 + ch, by0 - ch, by1 + ch, z0)], True),
            box(bx0 - ch, bx1 + ch, by0 - ch, by1 + ch, zb - 1, z0 + 0.01)]
    keep = []
    for xa, xb, y, r in pilots:
        rk = r + s.get("pilot_wall", 1.0)
        keep += [Part.makeCylinder(rk, z1 - zb + 4, V(x, y, zb - 2)) for x in (xa, xb)]
        keep.append(box(min(xa, xb), max(xa, xb), y - rk, y + rk, zb - 2, z1 + 2))
    cut.append(lead[0].fuse(lead[1:]).cut(Part.makeCompound(keep)))
    notch = wire_notch(s)
    if notch:
        nx0, nx1, hw = notch
        cut.append(box(nx0 - 0.01, nx1, -hw, hw, zb - 1, z1 + 1))
    bosses = []
    for xa, xb, y, r in pilots:
        a, b = V(xa, y, zb - 1), V(xb, y, zb - 1)
        cut += [Part.makeCylinder(r, z1 - zb + 2, a), Part.makeCylinder(r, z1 - zb + 2, b)]
        if abs(xb - xa) > 0:
            cut.append(box(min(xa, xb), max(xa, xb), y - r, y + r, zb - 1, z1 + 1))
        rt = r + BOSS_WALL
        for x in sorted({xa, xb}):
            bosses.append(Part.makeCone(rt + hb, rt, hb + 0.01, V(x, y, z0 + 0.01), V(0, 0, -1)))
    clip = box(x_ext[0], x_ext[1], y_ext[0], y_ext[1], zb - 0.5, z0 + 0.5)
    boss = bosses[0].fuse(bosses[1:]).common(clip) if hb > 0 else None
    return plate, cut, boss


# Where each plate and horn pocket ended up (for the verification script): name -> placement.
PLATES = {}
HORNS = {}


def _teardrop(r, up, z0, z1):
    """45 deg roof over a circle of radius r centred on the local z axis, pointing along up (2D)."""
    ux, uy = up
    px, py = -uy, ux                      # perpendicular
    k = r / math.sqrt(2)
    pts = [(k * px + k * ux, k * py + k * uy), (r * math.sqrt(2) * ux, r * math.sqrt(2) * uy),
           (-k * px + k * ux, -k * py + k * uy), (0, 0)]
    return prism(pts, V(0, 0, 0), (1, 0, 0), (0, 1, 0), (0, 0, 1), z0, z1)


def horn_pocket(horn, through=12.0, up=()):
    """Local frame: mounting face at z=0, part material at z<0, servo at z>0. Arm along x.

    up: the print-up directions in the face plane, as local 2D unit vectors along x or y.
    Each one gets 45 deg roofs on the pocket ceilings (arm lip, hub) and a teardrop on the
    centre access hole, so a pocket on a vertical face prints without support."""
    hl, hw, d = horn["len"] / 2, horn["width"] / 2, horn["depth"]
    rh = hw + 1.5
    arm = box(-hl, hl, -hw, hw, -d, 1)
    hub = Part.makeCylinder(rh, d + 1, V(0, 0, -d))
    centre = Part.makeCylinder(horn["centre"] / 2, through + 1, V(0, 0, -through))
    extra = []
    for ux, uy in up:
        if uy:     # roof along the arm's long edge (in the y-z plane, run along x)
            tri = [(uy * hw, -d), (uy * hw, 1), (uy * (hw + d + 1), 1)]
            extra.append(prism(tri, V(-hl, 0, 0), (0, 1, 0), (0, 0, 1), (1, 0, 0), 0, 2 * hl))
        else:      # roof at the arm tip
            tri = [(ux * hl, -d), (ux * hl, 1), (ux * (hl + d + 1), 1)]
            extra.append(prism(tri, V(0, -hw, 0), (1, 0, 0), (0, 0, 1), (0, 1, 0), 0, 2 * hw))
        extra.append(_teardrop(rh, (ux, uy), -d, 1))
        extra.append(_teardrop(horn["centre"] / 2, (ux, uy), -through, 1))
    cut = arm.fuse([hub, centre] + extra)
    if horn.get("pilot"):
        # self-tap pilots for the arm screws (match the printed horn; drill your own for a stock horn)
        for x in (-horn["len"] / 2 + HORN_SCREW_INSET, horn["len"] / 2 - HORN_SCREW_INSET):
            cut = cut.fuse(Part.makeCylinder(horn["pilot"] / 2, 5.0, V(x, 0, -horn["depth"] - 5.0 + 0.01)))
    return cut


HORN_SCREW_INSET = 3.5      # arm screw centre from the arm tip
HORN_CLEAR = 0.15           # printed horn clearance in its pocket (per side)
SPLINE_CLEAR = 0.1          # radial clearance on the printed spline socket; tune to your printer


def spline_socket(sp, length):
    """Internal spline (star polygon, triangular teeth) along +z from z=0, in local coords."""
    import math
    n, r_out = sp["n"], sp["d"] / 2 + SPLINE_CLEAR
    r_in = r_out - sp["tooth"]
    pts = []
    for i in range(2 * n):
        a = math.pi * i / n
        r = r_out if i % 2 == 0 else r_in
        pts.append(V(r * math.cos(a), r * math.sin(a), 0))
    pts.append(pts[0])
    return Part.Face(Part.makePolygon(pts)).extrude(V(0, 0, length))


def printed_horn(servo):
    """Horn that fits horn_pocket(servo['horn']) exactly, with a moulded spline socket.

    Local frame matches horn_pocket: part face at z=0, arm sunk to z=-depth, servo at +z,
    spline top at z=hub. Returned arm-down (z from 0) ready to print, socket facing up.
    """
    h, sp = servo["horn"], servo["spline"]
    c = HORN_CLEAR
    arm = box(-h["len"] / 2 + c, h["len"] / 2 - c, -h["width"] / 2 + c, h["width"] / 2 - c, -h["depth"], 0)
    top = h["hub"] + sp["engage"]
    hub = Part.makeCylinder(h["width"] / 2 + 1.5 - c, top + h["depth"], V(0, 0, -h["depth"]))
    shape = arm.fuse(hub)
    sock = spline_socket(sp, sp["engage"] + 1)
    sock.translate(V(0, 0, h["hub"]))
    cuts = [sock, Part.makeCylinder(sp["screw"] / 2, top + h["depth"] + 2, V(0, 0, -h["depth"] - 1))]
    for x in (-h["len"] / 2 + HORN_SCREW_INSET, h["len"] / 2 - HORN_SCREW_INSET):
        cuts.append(Part.makeCylinder(h["arm_screw"] / 2, h["depth"] + 2, V(x, 0, -h["depth"] - 1)))
    shape = shape.cut(Part.makeCompound(cuts)).removeSplitter()
    shape.translate(V(0, 0, h["depth"]))
    return shape


def bearing_housing_cut(face_out, axis, plate_t=RING_BRG_PLATE_T):
    """Cut for a 623 pocket from an outer face plus a lip hole. face_out on the axis, axis points outward."""
    a = V(axis).normalize()
    pocket = cyl(BRG_POCKET / 2, face_out - a * BRG_W, face_out + a * 1)
    lip = cyl(LIP_HOLE / 2, face_out - a * (plate_t + 1), face_out)
    return pocket.fuse(lip)


def bearing_envelope(face_out, axis):
    a = V(axis).normalize()
    outer = cyl(BRG_OD / 2, face_out - a * BRG_W, face_out)
    return outer.cut(cyl(1.5, face_out - a * (BRG_W + 1), face_out + a))


def axle_boss(face, axis, length, pilot_depth):
    """Boss on a rotating part reaching the bearing inner race; axis points from part toward bearing."""
    a = V(axis).normalize()
    boss = cyl(AXLE_BOSS_D / 2, face - a * 0.5, face + a * length)
    pilot = cyl(M3_PILOT / 2, face + a * (length - pilot_depth), face + a * (length + 1))
    return boss, pilot


# --- parts -----------------------------------------------------------------
def max_radius(shapes, axis):
    """Largest distance of any (tessellated) point from an axis through the origin."""
    a = V(*axis).normalize()
    r = 0.0
    for shp in shapes:
        for p in shp.tessellate(0.2)[0]:
            r = max(r, (p - a * p.dot(a)).Length)
    return r


def sensor_body():
    """Stack parts and board envelopes, moved so the roll axis is the X axis."""
    za = ss.axis_z()
    up = V(0, 0, za)
    # the middle deck prints flat, walls up: world +z is local +y on the horn face
    h_o, h_x, h_z = V(BODY_HALF_X, 0, 0), (0, 1, 0), (1, 0, 0)
    horn = placed(horn_pocket(MG90S["horn"], through=ss.WALL_T + ss.RIB_D + 2, up=[(0, 1)]), h_o, h_x, h_z)
    HORNS["stack_middle_deck"] = dict(horn=MG90S["horn"], origin=h_o, x=h_x, z=h_z)
    boss_len = RING_GAP + (RING_BRG_PLATE_T - BRG_W)
    boss, pilot = axle_boss(V(-BODY_HALF_X, 0, 0), (-1, 0, 0), boss_len, boss_len + ss.WALL_T - 0.5)
    for c in (horn, boss, pilot):
        c.translate(up)
    lower, upper = ss.spines()
    parts = [("stack_middle_deck", ss.middle_deck(horn, boss, pilot)),
             ("stack_top_deck", ss.top_deck()),
             ("stack_bottom_deck", ss.bottom_deck()),
             ("stack_spine_upper", upper),
             ("stack_spine_lower", lower)]
    refs = ss.boards()
    for _, shp in parts + refs:
        shp.translate(-up)
    return parts, refs
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

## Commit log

2026-10-07 Swirly-grid plate generator and fit checker
    Port of tannewt/swirly-grid slot geometry to FreeCAD, plus a hole-pattern
    fit checker and matplotlib preview.
    [swirly-plate-2x4.FCStd, swirly-plate-2x4.step, swirly-plate-2x4.stl]
2026-10-07 Feather-boss sensor carrier and mechanical reference data
    Carrier puts the ISM330DHCX on the #4569 FeatherWing over the plate
    centre (future gimbal axis intersection). Adds parsed board hole/IC
    positions for the PR 839 sensors and servo dimensions.
    [carrier-swirly-2x4-feather.FCStd, carrier-swirly-2x4-feather.step, carrier-swirly-2x4-feather.stl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]
2026-10-08 Pan/tilt/roll gimbal layout v1 with clearance sweeps
    Roll cradle, tilt ring (MG90S 16 mm and 21 mm tab-height variants),
    pan yoke for a standard tilt servo, and base for the pan servo. 623ZZ
    idlers on roll and tilt. Each stage is swept 360 deg against the next
    for collisions.
    [base.step, base.stl, imu-gimbal-assembly.FCStd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]
2026-10-08 Sensor box holding every board on four swirly-grid faces
    Replace the single-Feather carrier and roll cradle with a square tube
    whose four faces are 3x5 swirly grids: FeatherWing + 1 QT on top, 4
    portrait QT boards on each other face (13 QT + wing). End caps carry the
    MG90S roll horn and idler axle. Ring and yoke clearances are now sized
    from the measured sweep radii; yoke gets outer gussets.
    [base.step, base.stl, imu-gimbal-assembly.FCStd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]
2026-10-08 Layered sensor stack with open sides and a roof to strike
    Replace the closed sensor box with three stacked 4x4 swirly-grid decks
    on corner pillars (15 QT + FeatherWing). Deck 0 doubles as the roll
    cradle; the top deck has a central post with a 45-degree flared roof as
    the striker target. Every part prints upright without supports.
    [base.step, base.stl, imu-gimbal-assembly.FCStd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]
2026-10-08 Cam-driven tap striker; centre-deck-only gimbal mount, 4 boards across
    Stack: 5x4-cell decks with 4 portrait QT per row (21 QT + wing). Only the
    middle deck carries the roll walls; top and bottom decks hang off central
    spines under the roof.
    Striker: PETG hairpin leaf printed with a 2 N preload in its free shape,
    lifted by a two-lobe cam on a 270-degree servo via a folding pawl so the
    servo can reverse to re-arm. Spring shapes come from a moment-curvature
    model; checks report roll/tilt range with the striker fitted.
    [base.step, base.stl, imu-gimbal-assembly.FCStd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]
2026-10-08 Striker hammer hovers ~0.8 mm off the roof at rest
    The cam base circle now holds the pawl so the hammer rests clear of the
    roof; strikes land by let-off (arm overshoot through the gap). The pawl
    leans 8 degrees into a matching stop so the resting load holds it there
    instead of folding it.
    [base.step, imu-gimbal-assembly.FCStd, pan_yoke.step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]
2026-10-08 Servo measurement drawing (dimensions to confirm)
2026-10-08 Use measured MG90S and DS3240MG dimensions
    Hand-measured servo dimensions replace the datasheet guesses. Mount
    heights use the directly measured tab-top-to-spline-top (MG90S 12.0,
    DS3240 14.0). The MG90S tab-height variants collapse to one tilt ring.
    The servo drawing now shows measured values; horns are still to measure.
    [base.step, base.stl, imu-gimbal-assembly.FCStd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]
2026-10-08 Printed horns and spline cam alongside stock-horn pockets
    Each horn pocket now has arm-screw pilots and also accepts a printed
    horn (horn_mg90s_printed 21T, horn_ds3240_printed 25T) shaped to fill
    it exactly, with a moulded spline socket (SPLINE_CLEAR tunes the fit).
    The striker gets a striker_cam_spline variant with the 21T socket
    moulded in. DS3240 tab hole confirmed at 4.5 mm.
    [base.step, horn_ds3240_printed.step, horn_ds3240_printed.stl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]
2026-10-08 Assembly render and print list
2026-10-08 Print list: nozzle size per part
2026-10-10 tall_top variant: 20 mm upper spine, striker raised; fix spine names
    Variant built from the same scripts: STACK_UPPER_GAP raises the top deck
    while the middle deck, roll axis, ring, yoke and base stay pinned to the
    main build (build_info.json). The striker rides up with the roof; only
    the stand's pad seat grows, so travel and forces are unchanged. Tilt range
    with the striker improves to -70/+65 deg.
    Also fixes stack_spine_upper/lower being exported under each other's
    names.
    [base.step, base.stl, horn_ds3240_printed.step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]
2026-10-10 tall_top variant: 25 mm upper spine (striker raised 7.9 mm)
    Pinned variants may now use part of the sweep margin (min 1.5 mm); the
    taller top deck clears the base ring by 2.4 mm through a full roll.
    [base.step, horn_ds3240_printed.step, horn_mg90s_printed.step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]
2026-10-10 Fixings list (per axis, with totals and non-magnetic note)
2026-10-10 Shopping list: one M2.5 kit for the 12 mm nylon screws
2026-10-10 Shopping list: board fixings moved to slow shipping
2026-10-10 Fit fixes from the first print: notches, lead-ins, pilot bosses, horn wall
    Servo plates (servo_plate): wire notch at the spline end (DS3240 8 mm wide to
    the tab end, MG90S 6 mm, both opening the nearest pilot as a mouse ear with
    >= 240 deg of wall left), 0.4 mm cut-out clearance, 1 mm lead-in chamfers on
    both faces, and 45 deg cone bosses doubling the thickness round every tab
    pilot. Bosses also at the striker-stand bolts, stack bolts, bench holes and
    the yoke's horn-arm pilots; 623 lips 2.4 mm.
    Middle deck end walls 6 mm, carried above the horn arm with a rib and boss
    behind the hub; horn pockets get 45 deg roofs and teardrop access holes for
    their print orientation. Lightening windows in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
    [make_gimbal.py]
2026-10-10 Regenerate main parts and assembly after the fit fixes
    [base.step, base.stl, horn_ds3240_printed.step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]
2026-10-10 tall_top: regenerate on the fixed main design; bolt grip with deck bosses
    [base.step, base.stl, horn_ds3240_printed.step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]
2026-10-10 README: fit fixes, mouse-ear pilots, insertion faces, assembly order, fixings
2026-10-10 Striker redesign: rigid hammer arm on a tower, parks clear of the full tilt sweep
    The hairpin bar hovered 0.85 mm over the roof and limited tilt to +/-55 deg.
    The striker now stands on a tower on the yoke's idler upright (same 4 x M3):
    - a rigid 2.5D hammer arm on an M3 pivot (printed bushing + spacers), 66 mm
    above the roof, parks 48 deg up, >= 7.9 mm from everything that moves
    - a vertical PETG drive leaf, pinned (M3) to the arm's tail, drives it down
    onto a rest stop with a bumper lip; the head hovers HOVER = 5 mm over the roof
    - the hammer head sits on a lost-motion PETG leaf, preloaded 1.4 N against a
    nylon stop screw (2.0 N at contact); let-off overshoot 15.5 mm (>= 3 x gap)
    - 27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
    [make_gimbal.py]
2026-10-10 Regenerate main parts and assembly with the new striker
    New prints: striker_arm, striker_spring, striker_bushing, striker_spacer (x2).
    Changed: striker_stand (now the tower), striker_pawl (14 mm), striker_cam /
    striker_cam_spline (new lobe profile). striker_bar is gone. The other parts
    are unchanged (STEP headers only). build_info.json now carries the striker
    numbers and its clearance results.
    [base.step, horn_ds3240_printed.step, horn_mg90s_printed.step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]
2026-10-10 tall_top: regenerate on the new striker (pinned to the main build, 25 mm)
    Only stack_spine_upper and striker_stand differ from the main design: the
    tower is 7.9 mm taller and the whole mechanism rides up with the roof.
    Striker parked: tilt clear through 360 deg (min 7.9 mm), roll +/-90 16.3 mm,
    tilt x roll 7.9 mm; at rest the head is 5.0 mm over the roof. The old M3 x 22
    pad screws are no longer needed. README and change image updated.
    [base.step, horn_ds3240_printed.step, horn_mg90s_printed.step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]
2026-10-10 README and shopping list: new striker section, print list, fixings, assembly
    Striker section rewritten (mechanism, numbers, clearance table for main and
    tall_top), print list (striker_arm, striker_spring, bushing, spacers; reprint
    the pawl), fixings (M3 x 50 pivot, M3 x 20 drive pin, 4 x M3 x 16 leaf pad,
    nylon M3 x 30 stop screw + 2 nylon nuts), assembly order and envelope.
    New renders: docs/striker-redesign-changes.png (vs 618ebb1) and
    docs/striker-section.png (x = 0: rest, parked, as printed, tilt sweep).
    No springs or rubber bands to buy.
2026-10-11 Animated step-by-step assembly with every fixing
    - fixings.py: simple Part models of the screws, nuts, washers, spacers,
    standoffs, 623ZZ bearing and filament pin.
    - The generators now record a fixing point (seat, axis, hole, depth) wherever
    they cut a fixing hole. make_gimbal.geometry() builds everything without
    writing files, and the part geometry is unchanged.
    - assembly_plan.py places every fixing on those points. It sets 25 steps,
    insertion paths and sub-assembly moves.
    - assembly_checks.py checks:
    - (a) counts against the README
    - (b) coaxial with the real hole faces
    - (c) seated
    - (d) shank clearance
    - (e) access on the animation timeline
    - make_assembly_animation.py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
2026-10-11 Animated assembly: keep each shape's own placement
    write_document() set o.Placement = it.placement after assigning the shape,
    which threw away the placement the shape carries itself. Every servo
    envelope, horn, board reference, bushing and spacer (shapes placed with
    make_gimbal.placed()) was saved at the origin in the FCStd, although the
    GIF and checks (which use Item.world_shape()) were right.
    Regenerated the main and tall_top documents (ASSY_RENDER=0); the macro dry
    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
2026-10-11 Live design: jointed Assembly with Simulations and a striker motion model
    striker_motion.py works the striker's motion out from make_striker's model:
    - cam angle -> arm angle: the smallest arm angle at which the pawl (a
    capsule on the drive leaf, bent for that angle by the solve() cantilever)
    clears the cam profile (cam_radius, LOBES);
    - reverse stroke: the arm can't rise; the pawl folds just enough to clear;
    - release: RK4 drop of arm + leaf tip onto the rest stop (55.0 mJ, design
    54.7), then the head-leaf let-off to the roof (28.0 mJ, design 27.5);
    - the programme: park, pan +/-135, tilt 360, roll +/-90, re-arm, park,
    single tap, re-arm, double tap, rest (38.2 s), sampled as a time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
2026-10-11 Mechanism animation macro and motion checks
    docs/motion/animate_motion.FCMacro plays the programme in the GUI
    (|< < Play/Pause > >|, time scrub, section list, 0.1x-4x speed, caption in
    the dialog, status bar and 3D view; MotionAnim.goto/play/pause/stop). It
    poses the components about the Assembly's own joint axes, swaps the drive
    leaf (nearest degree) and arm (head leaf, nearest 0.5 mm) flex shapes, and
    carries the pawl and its pin on the leaf's station. It works on a temporary
    copy, or restores an open document exactly. Tested in a FreeCAD GUI process.
    check_motion.py, over the macro's dry run (1147 frames):
    - arm angle shown = timeline to 1.3e-11 deg; = the cam model recomputed
    per fram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
2026-10-11 Motion video, striker cycle plot, README "Live design and motion"
    render_motion.py renders the macro's own timeline headless (FreeCAD
    tessellation -> matplotlib): the whole rig, a striker close-up in the
    yoke's frame cut at x = 0, and a cam/pawl/leaf inset, with the caption.
    docs/motion/motion.gif (38.3 s, 383 frames, 9.3 MB) and motion.mp4
    (ffmpeg, 1.3 MB); frames can be rendered in parallel chunks.
    striker-cycle.png plots cam angle, cam radius under the pawl, arm angle,
    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
2026-10-11 Servo control spec: axes, ranges, cam angles, tap procedures
2026-10-11 Add servo bench controls and record pulse calibration
2026-10-11 Save gimbal CAD and print exports
2026-10-12 Striker: MG995 cam drive, two-lobe cam, pin kept on its slot
    - MG995 dict (datasheet values, marked to measure) mounted on the tower's
    +X wall, gear face -X: increasing pulse (anticlockwise from the gear face,
    as benched) is the model's forward, rest at 500 us.
    - Cam: two lobes (15,65,73) and (97,147,151) on a 12 mm base circle, so a
    double tap is one sweep (~0.21-0.26 s between drops) and the pressure
    angle stays <= 36 deg. Follower at 48 mm, pawl 17 mm.
    - Drive leaf solved with the pin on its slot centreline at every pose
    (was up to 1.8 mm off); the tail leans back 28 deg so the pin only dips
    ~2 mm along the slot and slot friction costs 6.3 mJ, not ~23. The leaf is
    sized to s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
2026-10-12 Servo spec and examples: MG995 cam angles and pulses
    - docs/servo_control.md: MG995 (rest 0 = 500 us, forward = increasing
    pulse, anticlockwise from the gear face), the two-lobe angles and nominal
    pulses (park 69 = 1267, single tap 87 = 1467, double-tap end 165 = 2333),
    release margins, double-tap interval, and an MG995 calibration procedure.
    - examples: cam travel 180 / direction +1, PARK_A / RELEASE_A / RELEASE_B
    from the new cam, double tap as one full-speed move, park always via
    rest (a reverse move folds the pawl). The pulse controller defaults to
    the double-tap end and caps at the MG995's nominal 2500 us.
    CALIBRATED stays False; nothing was run on hardware.
    Co-Authored-B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
2026-10-12 Animated assembly: MG995 fixings, tower before the servo, tab-screw access
    - assembly_plan: 4 x M3 x 12 self-tap MG995 tab screws, M3 cam centre
    screw, horn trimmed to 18 mm, cam slid in from behind and onto the spline
    from -X. The tower now goes on the yoke before the MG995 (its body blocked
    the +X upper tower bolt's hex-key path).
    - Tower: 7.2 mm teardrop driver holes through the -X wall in line with the
    MG995 tab screws; tab pilots slotted 48.6-49.3 x 9.75 so the coaxial check
    passes (0.175 mm).
    - Checks: counts match the README (M3 x 12 self-tap 12, MG90S tabs 2), seats
    and shanks OK, no blocked insertions; only the bench screws need an angled
    driver, as before.
    - Regenerat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
2026-10-12 README, shopping list, tall_top: MG995 cam drive
    - README striker section: how the MG995 drive works, the torque budget
    against the edfadd7 MG90S cam (1.53 vs 1.46 kg cm; 18 % vs 81 % of
    stall), the pin/slot fix and its check numbers, clearances, print list
    (reprint stand, arm, spring, pawl, cam), fixings and totals (4 x M3 x 12
    tab screws, M3 cam centre screw), assembly order (tower before servo),
    animation steps, live-design results, envelope and mass.
    - Shopping list: the MG995 and its screws.
    - tall_top: README note and its animated assembly.
2026-10-12 Live design: MG995 cam joint, new programme, motion checks
    - make_motion: cam joint 0-180 deg (forward = increasing pulse), park at
    lobe 1 (69 deg), verification poses inside the MG995 travel.
    - striker_motion programme (committed with the model): park 69, single tap
    72 -> 87, double tap 72 -> 87 and 150 -> 165, releases at 375 deg/s.
    - Rebuilt docs/motion/imu-gimbal-motion.FCStd (view providers re-attached
    in the GUI), motion-model.json, verify-joints.json (FK drift 7.7e-14 mm,
    simulations to 4e-8 deg).
    - check_motion: 0 collisions over 11,197 pair checks; drive pin in its slot
    0.000 mm^3 in every frame (was 27 mm^3); parked clearance 7.90 mm; arm
    angle vs the cam model 1.2e-4 d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
2026-10-12 Web Serial servo console: 8-channel firmware + static page
    code.py attaches to the PCA9685 without a reset and switches every output
    off at boot (NVM toggle). Per-channel angle/us/duty, end stops, sweeps
    with rate and cycles, sequences, tilt/roll interlock on the hammer cam.
2026-10-12 GitHub Pages: landing page and servo console
2026-10-13 Servo console: interlock optional (off), never blocks centre/rest/off; robust loop
    Catch every error in the firmware loop so I2C glitches can't drop the board
    into the REPL (which silently swallowed SEQS and emptied the sequence
    buttons). Sequence list sent at startup and built into the page; page
    detects a REPL/crash and offers Restart firmware (Ctrl-C, Ctrl-D).
2026-10-16 Servo console: switch PCA9685 all-call off at init
    The PCA9685 powers up answering the all-call address 0x70, which clashes
    with a TCA9548A mux at its default address. Clear MODE1 bit 0 on every init.
2026-10-16 Servo console: PCA9685 at 0x41 (A0 bridged), fall back to 0x40
    Drops the all-call change from 29f4b79. The address actually used is
    reported in hello and STATUS (pca_address).
2026-10-16 WipperSnapper offline configs for PR 839 driver tests (one per mux)
